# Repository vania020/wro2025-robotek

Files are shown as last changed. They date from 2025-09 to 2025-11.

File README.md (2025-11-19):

# Ruwance - WRO 2025robotekPeru Flag

<p align="center">
  Banner Ruwance
</p>





+ Team Name: **Ruwance**
+ Car Name: **Kyra**
+ Club Name: **Robotek**
+ Team Members: **Isabella Gonzales & Vania Pachas**
+ Coach: **Anthony Valladolid**

---

*Welcome! 🎉* <br>
We are Team Ruwance, proudly representing Perú at the 2025 World Robot Olympiad! This GitHub repository contains the documentation, code, and full development journey of our autonomous vehicle, designed and built to compete in the Future Engineers Challenge.

# Repository Structure
* `t-photos` team photos (official one and funny one)
* `v-photos` photos of our vehicle (from every side, from top and bottom)
* `video` demonstration video link of the robot in the challenges
* `schemes` Wiring diagram with pins and electronic components
* `src` code of the robotic vehicle system
* `models` 3D printed parts and other chassis pieces 
* `other` Extra documentation

# Table of Contents
1. [Meet the Team!](#1-meet-the-team)
   
3. [Vehicle Overview](#2-vehicle-overview)
   + [General Description of the Car](#general-description-of-the-car)
   + [Versions of the Car](#versions-of-the-car)
     
4. [System Setup](#3-system-setup)
   + [Operating Environment Overview](#operating-environment-overview)
   + [Robot Operating System (ROS)](#robot-operating-system-ros-)
   + [Ubuntu](#ubuntu-)
   + [Raspberry Pi](#raspberry-pi-)
     
5. [Mobility Management](#4-mobility-management)
   + [Steering System - Ackermann](#steering-system--ackermann)
   + [Motor and Drivetrain](#motor-and-drivetrain)
   + [3D Pieces](#3d-pieces)
   
6. [Power & Sense Management](#5-power--sense-management)
   + [Power Source](#power-source)
   + [Sensors Integration](#sensors-integration)
   + [BOM (Bill of Materials)](#bom-bill-of-materials)
   + [Wiring Diagram](#wiring-diagram)

7. [Obstacle Management](#6-obstacle-management)
   + [Control Node Structure](#control-node-structure)
   + [Open Challenge](#open-challenge)
   + [Obstacle Challenge](#obstacle-challenge)
     
8. [Assembly Instructions](#7-assembly-instructions)
9. [Performance Videos](#8-performance-videos)
   
<br>

# Main Content

## 1. Meet the Team!
<table>
  <tr>
    <td width="55%" valign="top">
      <strong>Vania Pachas</strong><br><br>
      pencial <i>Responsible for Mechanical Design & Technical documentation</i><br>
       mail vaniaapachas@gmail.com<br>
       location Lima, Perú<br><br>
      Hi!! I'm Vania, an 18-year-old Peruvian passionate about innovation and STEM education. This is my first time in the WRO, and I'm excited to learn and take on this new challenge! I also love dancing salsa, crocheting, watching romcoms, and I’m a Quantum Computing enthusiast :)<br><br>
   
  <td width="45%" align="center">
    Vania
    </td>
  </tr>
  
</table>

<table>
  <tr>
    <td width="55%" valign="top">
      <strong>Isabella Gonzales</strong><br><br>
      pencial <i>Responsible for Electronics and Technical Designer documentation</i><br>
       mail isabellamilagros842@gmail.com<br>
       location Lima, Perú<br><br>
      Hello! My name is Isabella, I'm 16 years old, and I love robotics. I founded Robotek Perú, a club where students can learn robotics and join competitions, and this is my second time at the WRO. My favorite hobbies are singing with my choir, practicing taekwondo, and art. <br><br>
   
  <td width="45%" align="center">
    Isa
    </td>
  </tr>
  
</table>

<br>

> [!NOTE]
> 🤔Why is our team named *Ruwance*?<br><br>
> The name *Ruwance* comes from combining the Quechua word "**ruway**" and the English word "**chance**". Ruway means "to create" or "to do", which really reflects who we are, a team that is always making, building, and experimenting. As students of Robotek from Lima, Peru, we have learned that creativity and resilience are important traits to succeed in and enjoy our robotics journey.

<br>

## 2. Vehicle Overview
This is our car named **Kyra**, it is the result of multiple versions and modifications since 2024:) Since then, we have been studying, learning and testing different methods to improve our car. It has been an interesting and challenging journey in robotics, but every effort was worth it!

<p align="center">
  Vehicle Overview
</p>

### **<ins>General Description of the Car</ins>**
Our autonomous vehicle is built to take on both the Open and Obstacle Challenges at the Future Engineers competition. Running on Ubuntu with ROS, it can process information and make decisions in real time. The car uses an Ackermann steering system and a custom-built chassis to move smoothly through turns and straight paths. A LiDAR sensor helps it detect the field walls, while the camera identifies traffic signs and obstacles. With this setup, the car can adapt its route, count laps, and complete the course efficiently.
<br>

| Front | Left | Right |
| :--: | :--: | :--: |
|  |  |   | 

| Back  | Top  | Bottom |
| :--: | :--: |:--: |
|  |  |   | 
> [!NOTE]
> Visit our [`v-photos`](https://github.com/vania020/wro2025-robotek/tree/main/v-photos) folder for more detailed photos of the car 📸🚗

### **<ins>Versions of the Car</ins>**
Our vehicle has gone through **10 versions** (and since we are always improving, there are still more to come!). It all started with a cardboard prototype, then moved on to acrylic and metal chassis designs, and later, we made personalized adjustments to a HiWonder kit. Along the way, we also experimented with different wheel designs, repositioned components, tested sensors like LiDAR, and finally adopted a new operating environment with ROS and Ubuntu.
<table>  
  <tr>
    <th width="10%">Version</th>
    <th width="40%">Car Photo</th>
    <th width="50%">Description</th>
  </tr>
  
  <!-- Version 1 -->
  <tr>
    <td align="center"><i>Version N°1</i></td>
    <td align="center">
      
    </td>
    <td>
      We built a cardboard prototype to test and understand the Ackermann steering system and wheel movement. This served as a reference to learn about the placement of components and systems.<br><br>
      <a href="v-photos/vehicle-versions/README.md#version-1">➡️ See more photos 🚗</a>
    </td>
  </tr>

  <!-- Version 2 -->
  <tr>
    <td align="center"><i>Version N°2</i></td>
    <td align="center">
    </td>
    <td>
      <br>We cut and incorporated an acrylic chassis and designed/3D-printed housing pieces for the camera, Ackermann system, and other components. The Ackermann used a stepper motor, and to perceive its surroundings, the car relied on infrared sensors and a webcam. 
      <br><br>The main controllers were a Raspberry Pi 4 and an Arduino Nano, powered by a power bank and lithium batteries. The car’s movement was driven by a single motor.<br><br> 
      <a href="v-photos/vehicle-versions/README.md#version-2">➡️ See more photos 🚗</a><br><br>
    </td>
  </tr>

  <!-- Version 3 -->
  <tr>
    <td align="center"><i>Version N°3</i></td>
    <td align="center">
    </td>
    <td>
      <br> We replaced the power bank with a smaller one, adjusted component placement into a two-level car system, and installed new wheels. Lithium batteries were replaced with higher-current ones, and the infrared sensors were moved to the front, so the vehicle could make more precise turns.<br><br>
      <a href="v-photos/vehicle-versions/README.md#version-3">➡️ See more photos 🚗</a><br><br>
    </td>
  </tr>

  <!-- Version 4 -->
  <tr>
    <td align="center"><i>Version N°4</i></td>
    <td align="center">
    </td>
    <td>
    <br> We upgraded the chassis to a modified HiWonder Kit and replaced the infrared sensors with a LiDAR for more accurate obstacle detection. The webcam was also switched to a monocular camera. The original car motor was replaced by two encoder motors, adapted with gears to drive a single wheel in compliance with competition guidelines.<br><br>

For the Ackermann steering, we replaced the stepper motor with a servomotor. On top of that, we moved away from the Arduino Nano and began implementing the ROS framework.<br><br>
<a href="v-photos/vehicle-versions/README.md#version-4">➡️ See more photos 🚗</a><br><br>
    </td>
  </tr>

  <!-- Version 5 -->
  <tr>
    <td align="center"><i>Version N°5</i></td>
    <td align="center">
    </td>
    <td>
      <br>Our main improvement was the chassis. We joined the two bases by drilling them together and carefully organized the components with the Raspberry Pi inside. The LiDAR was placed on top so nothing would block its view, and we also completed and installed the camera housing.<br><br>
      <a href="v-photos/vehicle-versions/README.md#version-5">➡️ See more photos 🚗</a><br><br>
    </td>
  </tr>

  <!-- Version 6 -->
  <tr>
    <td align="center"><i>Version N°6</i></td>
    <td align="center">
    </td>
    <td>
      <br> Wheels were changed to adjust the car’s height so the Lidar could detect walls within the 10 cm range (previously it was too high and failed). The housing material was upgraded from PLA to polycarbonate for greater resistance, and the Open Challenge (autonomous 3 rounds driving) was completed.<br><br>
      <a href="v-photos/vehicle-versions/README.md#version-6">➡️ See more photos 🚗</a><br><br>
    </td>
  </tr>

  <!-- Version 7 -->
  <tr>
    <td align="center"><i>Version N°7</i></td>
    <td align="center">
    </td>
    <td>
      <br> Using our HiWonder kit as the base, we designed and cut a completely new, smaller chassis with personalized mounting holes for all components, new housing pieces were created, and the two-motor system was replaced by a single motor in a gear system.<br><br>
    We also moved from a two-level structure to a single-level layout, placing all the components on the same surface to give the Raspberry Pi better airflow and easier access. The car successfully detected and avoided the first traffic signs.<br><br>
      <a href="v-photos/vehicle-versions/README.md#version-7">➡️ See more photos 🚗</a><br><br>
    </td>
  </tr>

  <!-- Version 8 -->
  <tr>
    <td align="center"><i>Version N°8</i></td>
    <td align="center">
    </td>
    <td>
      <br> <b>Car dimensions:</b> 15 x 23 cm <br><br>
      We 3D-printed new, slimmer front wheels because the original ones stuck out too much from the chassis. A custom housing was also printed for the batteries, and most importantly, the Ackermann steering servo was mounted vertically to save space and allow for a wider turning angle.<br><br>
During previous testing, we realized the LiDAR was struggling to properly detect the walls of the field, so we 3D-printed and implemented a small angled mount to give it a slight tilt.<br><br>
      <a href="v-photos/vehicle-versions/README.md#version-8">➡️ See more photos 🚗</a><br><br>
    </td>
  </tr>

<!-- Version 9 -->
  <tr>
    <td align="center"><i>Version N°9</i></td>
    <td align="center">
    </td>
    <td>
      <br> <b>Car dimensions:</b> 15 x 20 cm <br><br>
In this version, the components were arranged more efficiently to save space. We added a custom housing for the batteries, placed the Pi5 controller on top, and mounted the Raspberry above it, creating a layered system.<br><br>
A new chassis base was printed in MDF, and the Ackermann was moved slightly because, in the previous version, the rack was colliding with the servo. To improve traction, we added a groove to the wheels and printed small cylinders between them to prevent contact with the screws. With these adjustments, the robot managed to complete a lap in <b>20 seconds</b>.<br><br>
      <a href="v-photos/vehicle-versions/README.md#version-9">➡️ See more photos 🚗</a><br><br>
    </td>
  </tr>

  <!-- Version 10 -->
  <tr>
    <td align="center"><i>Version N°10</i></td>
    <td align="center">
    </td>
    <td>
      <br> <b>Car dimensions:</b> 15 x 18 x 16 cm <br><br>
We removed the LiDAR housing because, after testing the robot multiple times, we found that vision worked better without it. We also printed the rear wheels, so now all wheels are the same. We modified the gear system, which allowed the robot to complete the 3 laps faster. It now takes less than 10 seconds to complete an entire lap, and it manages to complete the 3 laps in 28 seconds. The small and big gears were interchanged so that the big gear is directly attached to the motor shaft.<br><br>
  <a href="v-photos/vehicle-versions/README.md#version-10">➡️ See more photos 🚗</a><br><br>
    </td>
  </tr>

</table>

<br>

> [!NOTE]
> Visit our [`vehicle-versions`](v-photos/vehicle-versions/README.md) folder to see photos and videos of our car evolution 🔝

<br>

## 3. System Setup
### **<ins>Operating Environment Overview</ins>**
The operating environment of our robotic car is designed as a structure that connects hardware, software, and middleware into a single functional system, shown in the diagram below:

<p align="center">
  diagram
</p>

### **<ins>Robot Operating System (ROS)</ins>** ROS
ROS is a framework that connects a robot’s software and hardware, making sensors, motors, and programs work together so the robot can perform tasks smoothly. For this project, we use ROS 2 Jazzy, one of the latest versions of ROS 2. You can find the documentation here:  [ROS 2 Documentation: Jazzy](https://docs.ros.org/en/jazzy/index.html)<br>

Without ROS, everything would have to be written in one long, complicated program that’s hard to manage. We can now divide the system into smaller parts, or nodes, that each do one job, making the system easier to build, fix, and expand.<br>

<p align="center">
  Nodes
</p>

> This is an official animation to better understand how nodes work. Each node does one clear job, like moving wheels or reading sensors, and they talk to each other using topics, services, actions, or parameters.
>  In practice, this is the process:
> 1. Sensors send data to ROS 2 by publishing it on topics.
> 2. Other nodes listen to that data, process it, and decide what the car should do.
> 3. Finally, a controller node sends commands, making the car move accordingly.

<br>

*<ins>Why we use ROS?</ins>*<br>

<table>
  <tr>
    <td><b>Sensor & Actuator Integration</b></td>
    <td>
      ROS connects all sensors and actuators in one system, ensuring seamless coordination. 
      This gives our autonomous car continuous information about its surroundings 
      and optimizes overall performance.
    </td>
  </tr>
  <tr>
    <td><b>Environmental Perception with LiDAR</b></td>
    <td>
      Most manufacturers of advanced sensors, such as LiDARs, provide an official package to use their hardware with ROS. In the case of the DTOF STL-19P, the manufacturer provides a package that automatically publishes the LiDAR data so it can be processed afterward.
    </td>
  </tr>
  <tr>
    <td><b>Support with Python</b></td>
    <td>
      ROS is fully compatible with Python, which allows for versatile and high-level code development. In addition, being open-source, it has a large community that provides support and assistance for robot development.
    </td>
  </tr>
  <tr>
    <td><b>Debugging & Simulation</b></td>
    <td>
      ROS includes tools to quickly debug the content published on topics. It also provides tools such as RViz, which allows real-time data visualization, and Gazebo, which enables running simulations.
    </td>
  </tr>
  <tr>
    <td><b>Efficient Simulation & Debugging</b></td>
    <td>
      Virtual environments like 
      <a href="https://gazebosim.org/home">Gazebo</a> let us fine-tune parameters before implementation. 
      Tools like 
      <a href="https://docs.ros.org/en/humble/Tutorials/Intermediate/RViz/RViz-User-Guide/RViz-User-Guide.html">RViz</a> 
      allow real-time visualization of sensor data and car status, making debugging much easier.
    </td>
  </tr>
</table>

<br>

### **<ins>Ubuntu</ins>** UBUNTU
Ubuntu is a popular, free, open-source operating system based on Linux. It is known for being reliable, flexible, and widely used in both research and industry. In our project, we use Ubuntu 24.04 as the **foundation that runs on the Raspberry Pi**.<br>

Ubuntu manages the Raspberry Pi’s resources efficiently, ensuring it runs correctly. It provides drivers and compatibility for sensors and external hardware, making integration easier. Ubuntu also allows us to install and run ROS 2 Jazzy and gives us access to important libraries and tools that simplify tasks such as sensor communication and system development.<br>

We use Ubuntu because of its stability and compatibility with ROS 2 Jazzy. Since ROS 2 packages are officially distributed for Ubuntu, using this operating system guarantees that we can easily install and manage the software needed for our car.
<br><br>

### **<ins>Raspberry Pi</ins>** Raspberry
The Raspberry Pi is a small computer that works as the brain of our car. It is powerful enough to run Ubuntu, ROS 2, and our algorithms in real time. In our project, we use the Raspberry Pi 5, which you can find here: [Raspberry Pi 5](https://www.raspberrypi.com/products/raspberry-pi-5/)<br>

**👉 Set up and configuration**<br>

With the [Raspberry Pi Imager](https://www.raspberrypi.com/software/), we flash Ubuntu 24.04 into the microSD card of the Raspberry. After that, we configure the basics like Wi-Fi, SSH for remote access, and hostname. And finally, we install ROS 2 Jazzy by following these steps: [Installation Ubuntu (deb packages)](https://www.google.com/url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)

| Step 1 | Step 2 | Step 3 | Step 4 |
| :--: | :--: | :--: |  :--: |
|  |  |  |  |

<br>

## 4. Mobility Management  

### <ins>**Steering System – Ackermann**</ins>

<p align="center">
  Ackermann
</p>

Our autonomous car uses an Ackermann steering system, controlled by a **15 kg·cm digital servo**, which provides precise and stable control for navigation and turns.  

The Ackermann steering geometry is designed to reduce tire slip by ensuring that all wheels align as radii of circles that share a common center when the car is turning. This configuration keeps the rear wheels fixed and places the center of rotation along a line extended from the rear axle. To achieve this geometry, the inside front wheel turns at a greater angle than the outside front wheel, allowing smoother and more efficient cornering.

---

### **Our own modifications ⚒️**

In the first versions of the car, we implemented the Ackermann steering system using a custom mechanism. We designed and 3D printed a gear connected to a stepper motor, along with a rack, which is a stick with grooves that fit into the gear teeth. When the motor rotated the gear, the rack would move, which in turn rotated the wheels.  

<p align="center">
  
  
</p>

One of the challenges we faced was the 3D printing process itself. Printing small details such as gear teeth was difficult and often imprecise, which caused problems in the initial prototypes. To solve this, we made the gear teeth larger, and while this worked mechanically, the final design ended up taking too much space inside the chassis.

For this reason, we decided to switch to the system we currently use, which is part of the **HiWonder kit**, adapted to fit in our chassis base. Instead of gears, it uses a system of linkages connected by screws and supported by bearings. These linkages move and transfer the motion to the wheels, achieving the Ackermann steering effect in a more compact way.

<p align="center">
  
</p>

> [!WARNING]
> At first, the Ackermann of the HiWonder kit worked fine — the car could turn and even get through some obstacles. But after a lot of testing, we noticed that whenever the car turned left, the Ackermann didn’t rotate as much as it did when turning right. This made obstacle avoidance harder, especially in the field corners, so we knew we had to make adjustments.

We realized that the servo needed to be repositioned. First, it was placed horizontally under the Ackermann linkages. We brainstormed how to make it more efficient and changed the position of the servomotor, mounting it vertically with the accessory facing downward under the chassis. This way, the linkages could move freely with more angles, and we also freed up extra space for the other components. This new placement also allowed us to reduce the length of the chassis.  

<table>  
  <tr>
    <th width="30%">Initial position</th>
    <th width="30%">Idea</th>
    <th width="30%">Final Position</th>
  </tr>
  <tr>
    <td align="center">
      
    </td>
    <td align="center">
      
    </td>
    <td align="center">
      
    </td>
  </tr>
  <tr>
    <td align="center">Servo mounted horizontally (limited angles)</td>
    <td align="center">Servo repositioned vertically</td>
    <td align="center">Final placement with improved steering</td>
  </tr>
</table>

---

### <ins>**Motor and Drivetrain**</ins>

<p align="center">
  
</p>

The drivetrain of our autonomous car is powered by a **25 mm metal gear DC motor**, chosen for its compact size and high torque. The motor is mounted on the chassis and directly connected to the rear axle through a system of gears, ensuring efficient transfer of power to the wheels.  

Our drivetrain includes a gear system:  
- The large gear is mounted on the motor shaft.  
- This large gear drives a smaller gear connected to the rear axle.  
- The result is an increase in the speed of the wheels.

<p align="center">
  
</p>

During assembly, we noticed a gap between the metal chassis part and the axle supports. This caused instability in the drivetrain. To fix it, we designed custom 3D-printed cylindrical spacers that fill the gap and keep the axle firmly in place. This simple solution reduces vibrations, prevents misalignment, and ensures smoother transmission of power from the motor to the wheels.

<p align="center">
  
</p>

---

### <ins>**3D Pieces**</ins>

This is the 3D model of our vehicle.  
Below, you will find a table with our 3D-printed parts and their descriptions.

<p align="center">
  
</p>

<table align="center" width="100%" style="table-layout: fixed;">
  <thead>
    <tr>
      <th width="30%">Component</th>
      <th width="40%">Preview</th>
      <th width="30%">Folder</th>
    </tr>
  </thead>
  <tbody>
    <tr>
      <td align="center"><b>Vehicle Base</b></td>
      <td align="center">
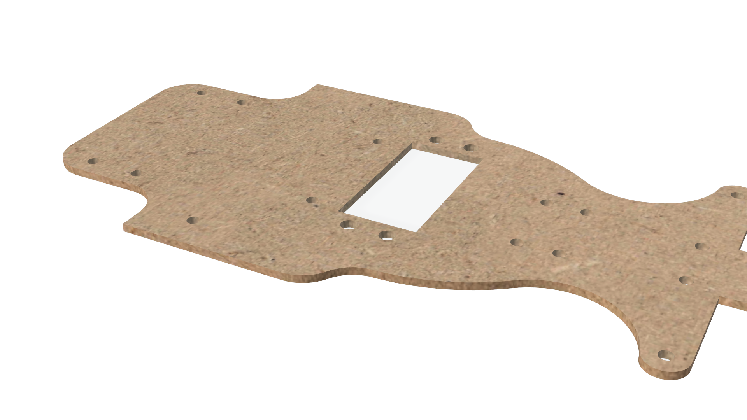
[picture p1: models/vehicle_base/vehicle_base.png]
        
      </td>
      <td align="center">
        <a href="models/vehicle_base/" target="_blank">View</a>
      </td>
    </tr>
    <tr>
      <td align="center"><b>Vehicle Wheels</b></td>
      <td align="center">
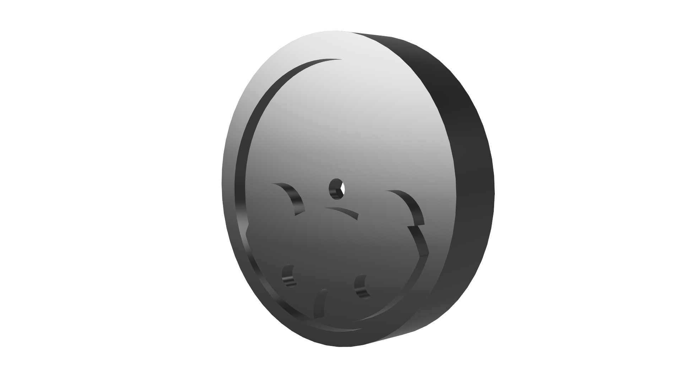
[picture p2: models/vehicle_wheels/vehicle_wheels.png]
        
      </td>
      <td align="center">
        <a href="models/vehicle_wheels/" target="_blank">View</a>
      </td>
    </tr>
    <tr>
      <td align="center"><b>Camera Housing</b></td>
      <td align="center">
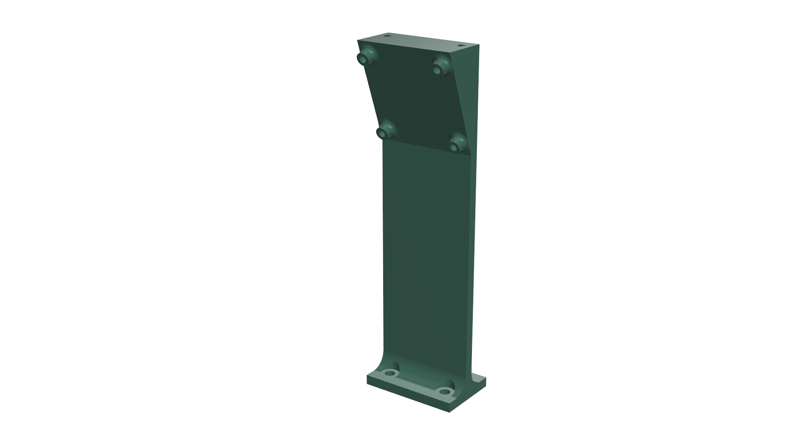
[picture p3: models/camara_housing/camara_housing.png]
        
      </td>
      <td align="center">
        <a href="models/camara_housing/" target="_blank">View</a>
      </td>
    </tr>
       <td align="center"><b>Raspberry Housing</b></td>
      <td align="center">
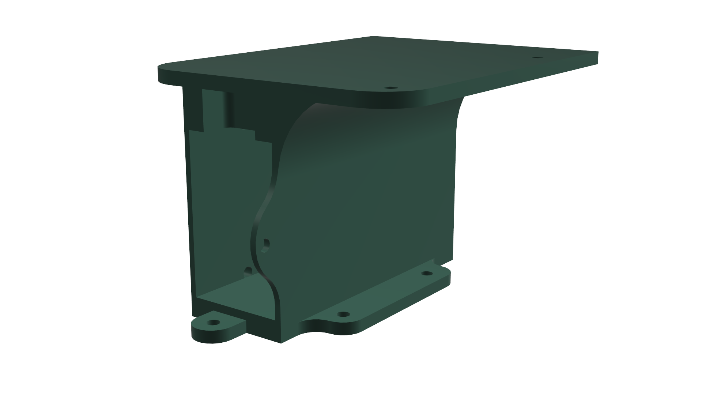
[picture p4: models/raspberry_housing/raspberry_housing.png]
        
      </td>
      <td align="center">
        <a href="models/raspberry_housing/" target="_blank">View</a>
      </td>
    </tr>
  </tbody>
</table>

## 5. Power & Sense Management 

### <ins>**Power Source**</ins>

<p align="center">
  
</p>

Our autonomous car is powered by 7.4V Li-Po batteries (2000mAh, 20C). We chose Li-Po batteries because they provide a high energy density, meaning more power in a small and lightweight package. The battery provides two main energy lines: one for the electronics and another for the motor: <br>

1. **Electronics & Sensors**  
   The battery first connects to the **RRC Lite Controller**, which regulates the power down to a safe **5 V**.  
   From there, it distributes electricity to:  
   - **Raspberry Pi 5** → acts as the brain of the car, running ROS 2 and processing sensor data.  
   - **Digital servomotor** → controls the Ackermann steering system.  
   - **STL-19P TOF LiDAR & monocular camera** → provide vision and distance perception.  

2. **Drive Motor (via L298N Motor Driver)**  
   In parallel, the battery also powers the **L298N motor driver** directly with **7.4 V**.  
   This driver regulates how much current goes to the **25 mm metal DC motor**, which is responsible for moving the car forward.  

By splitting the power into two paths (one regulated for sensitive electronics and one direct for the motor), the system ensures stability. Motors usually demand sudden spikes of current, and separating their supply avoids crashes or interruptions in the Raspberry Pi and sensors.

### <ins>**Sensors Integration**</ins>
To perceive its environment and handle the Future Engineers challenges, the car uses a combination of:  

- **STL-19P TOF LiDAR**: provides 360° distance data.  
- **2DOF Monocular Camera**: detects colors and obstacles.  

Together, these sensors give the robot a better understanding of its environment by combining depth perception with visual input.

### <ins>**STL-19P TOF LiDAR**</ins>

<p align="center">
  
</p>

<br>

Unlike simpler sensors such as ultrasonic or infrared, which measure only in a single direction and have limited precision, the LiDAR sensor is capable of a **360° scanning** and provides precise distance measurements by using laser pulses. It helps the robot map its surroundings over a wide range, detect obstacles, and navigate more accurately in dynamic environments.

<br>

| Characteristic | Vaue |
|---|---|
| Ranging distance | 0.03 – 12 m |
| Size | 38.59 x 38.59 x 34.8 mm |
| Scanning Angle | 360° |
| Scanning Frequency | 5 – 13 Hz |
| Ranging Accuracy | ±45 mm |
| Ranging Frequency | 5000 Hz |

> [!IMPORTANT]
> **📍Placement:**
> The LiDAR was positioned at an altitude of under 10 cm, so it can detect the walls of the path, which are also 10 cm high. This placement ensures the Lidar has a clear view of the obstacles while remaining unobstructed by other components. All other elements on the car were arranged to avoid blocking the Lidar’s line of sight. <br><br>
> 

### <ins>**2DOF Monocular Camera**</ins>

<p align = "center">
  
  </p>
<br>

The 2DOF Monocular Camera complements the LiDAR by adding visual perception. This allows the robot to recognize its environment beyond distance data, enabling future applications such as detecting the obstacles’ colors:

 + **Color detection**: Since graphical color detection is a core part of our  project, the camera can precisely identify various colors on the course. This allows our car to interact with the different traffic signs in the Obstacle challenge.
  + **Spatial awareness through data fusion**: When combining camera data with our sensor, the robot gains a richer understanding of its environment. The camera provides detailed visual context that leads to an adaptable navigation strategy.

> [!IMPORTANT]
> **📍Placement:**
> The camera is located in a special 3D mounting piece with a certain  inclination angle that points to the floor so it can better detect obstacles. At first it was placed at the front of the car but this location provided a limited vision and sticked out of the chassis lenght. See more detailed info of the housing piece in the [`3D Printed Parts`](#3d-printed-parts) section. <br><br> 
> 

### **<ins>BOM (Bill of Materials)</ins>**
| Component | Quantity | Description | Image |
|---|---|---|---|
| Raspberry Pi 5 | 1 | Main processing unit for running **ROS**. Acts as the main brain and the Host Controller of the system, capable of running operating systems and handling complex processing tasks. | Raspberry Pi 5 |
| RRC Lite Controller | 1 | Integrates: ROS expansion board, High-Frequency PID Control, Motor Closed-Loop Control, Servo Control and Feedback, IMU Data Acquisition, Power Status Monitoring, and a Power Switch. | Controller |
| STL-19P TOF Lidar | 1 | Provides precise, 360-degree distance measurements for real-time navigation and obstacle detection in dynamic environments. | Lidar |
| Lidar Adapter Board | 1 | Converts the LiDAR’s UART signals to USB for PC connection and data reading. | Adapter |
| 15 kg.cm Digital Servo | 1 | Provides accurate steering control. | Servo |
| 25MM Metal Gear Motor | 1 | Core drive motor for powering the wheels with torque and speed. | Motor |
| Suitcase Wheel Protector | 4 | Ensures 3d-printed wheels stability and grip on the floor. | tire |
| Monocular Camera | 1 | A camera used for capturing images and videos, can be used for computer vision or live streaming. | Camera |
| L298N Motor Driver | 1 | Controls motor direction and speed from the Raspberry Pi. | Motor Driver |
| Jumper Cables | 4–8 | Electrical connections between the motor driver and Pi. | Jumper Cables |
| USB-USB Cable | 1 | A cable to connect the Raspberry Pi to the camera, Lidar, and Controller. | USB Cable |
| Li-Po Battery 7.4 V 5000mAh 20C | 1 | A lithium polymer battery that provides portable, high-density power. | Battery |

### <ins>**Wiring Diagram**<ins>

The following visual wiring diagram illustrates the **physical connections** between the modules (Raspberry Pi, LiDAR, camera, motor, etc.) using **realistic component images**. It helps visualize the system layout and understand **how components are arranged and linked** in the robot.  

<p align="center">
  
</p>

#### **1. Raspberry Pi 5 Connections**
The Raspberry Pi 5 works as the brain of the car. Its USB ports connect the main sensors and the controller:

+ Camera → provides visual input for detecting traffic signs and colored obstacles.
+ LiDAR → provides distance and wall detection for navigation.
+ RRC Lite Controller → interfaces with the digital servomotor and forwards control signals to the motor driver.

<p align="center">
  
</p>

#### **2. RRC Lite Controller**
The RRC Lite Controller acts as a bridge between the Raspberry Pi and the actuators. It regulates incoming power from the Li-Po battery (down to a safe 5 V) and distributes it to:  
- The **Raspberry Pi 5**  
- The **digital servomotor** for Ackermann steering  

It also handles communication with the motor driver to send PWM control signals.

---

#### **3. Motor Driver and DC Motor**
The **L298N Motor Driver** is powered directly by the **7.4 V Li-Po battery**.  
- It regulates both the **speed** and **direction** of the **25 mm metal gear DC motor**.  
- The motor then powers the rear axle through a gear reduction system, increasing torque for smoother acceleration.  

---

#### **4. Power Source**
The **7.4 V Li-Po battery** supplies energy to the entire system, split into two paths:  
- **Direct line (7.4 V):** powers the L298N motor driver and DC motor.  
- **Regulated line (via RRC Lite Controller):** delivers 5 V to the Raspberry Pi, servomotor, and sensors.  

<br>

This is also a diagram that shows the **electrical wiring** and pin-level connections between all components — including power lines, GPIOs, and communication ports. It focuses on **signal paths and voltage levels** rather than physical appearance.  

<p align="center">
  
</p>

> [!NOTE]
> Visit our [`schemes`](https://github.com/vania020/wro2025-robotek/tree/main/schemes) folder to access all of our diagrams and schemes 🔑🚗

## 6. Obstacle Management 

### <ins>**Control Node Structure**</ins>

Since we use ROS 2 as the middleware that connects all the components of our autonomous vehicle, there isn't a single code that runs either the Open Challenge or the Obstacle Challenge. Instead, the system is built as a collection of independent but interconnected ROS 2 nodes, each performing a specific function such as reading the camera, processing LiDAR data, or controlling the motors. These nodes communicate constantly through topics and messages, allowing the car to behave as a cohesive, intelligent system.

You can access our custom node codes here:
<br>

| Node | Code Description | Function |
|---|---|---|
| 🛰️ Acker LiDAR Node | [`acker_lidar_node`](./src/acker_lidar_node) | Processes LiDAR scans and controls the robot. |
| 🎥 Camera Node | [`camara`](./src/camara) | Detects obstacles and colors. |
| ⚙️ Motor Node | [`motor`](./src/motor) | Sends PWM signals to control wheel speed. |

<p align="center">
  
</p>

This table better explains our ROS topics and messages:

| **Node** | **Role** | **Topic** | **Message Type** | **What It Transmits** |
| --- | --- | --- | --- | --- |
| **LiDAR Node** | Publisher | `/scan` | `sensor_msgs/LaserScan` | It sends 360° distance readings from the LiDAR; each value represents how far an obstacle is at a given angle. |
| **Camera Node** | Publisher | `/obstaculos` | `std_msgs/String` | It publishes the detected obstacle color in a text form: (`rojo`, `verde`, or `ninguno`), which defines how the main controller adjusts the steering setpoint. |
| **AckerLidar Node** *(Main Controller)* | Central Controller | `/motor_vel`, `/positionServo` | `std_msgs/Float32`, `ros_robot_controller_msgs/SetAckerServoState` | `/motor_vel`: Motor duty cycle (speed %). `/positionServo`: Steering position (PWM in µs) for Ackermann control. |
| **Motor Node** | Subscriber | `/motor_vel` | `std_msgs/Float32` | Receives motor velocity commands from the main controller and translates them into PWM signals for the DC motor driver (L298N). |
| **Raspberry Pi 5 Controller Node** | Subscriber | `/positionServo` | `ros_robot_controller_msgs/SetAckerServoState` | Executes servo position commands and moves the front wheels to reach the target angle. |
| **RRC Controller Button** | Publisher | `/button` | `ros_robot_controller_msgs/ButtonState` | Sends an activation signal when the onboard button is pressed, starting the robot’s control loop. |

### **What is a Message type?**

A **message type** is like a template that defines **what kind of data** is sent through a *topic*. For example, ROS already includes many built-in types, such as:

* `std_msgs/String` → used to send text.
* `std_msgs/Float32` → used to send a decimal number.
* `sensor_msgs/LaserScan` → used to send LiDAR data (distance readings around 360°).
* `geometry_msgs/Twist` → used to send linear and angular velocities (very common in mobile robots).
* And you can also have **custom message types**, like the ones included in your own package `ros_robot_controller_msgs`.

### **Important clarifiactions**

* For simplicity, **some topic names were shortened** in the diagrams.

  * The real ROS topic `/ros_robot_controller/acker_servo/set_state` is represented as **`/positionServo`**.
  * The real ROS topic `/ros_robot_controller/button` is represented as **`/button`**.

* The button input `/ros_robot_controller/button` is processed internally by the main node and does not appear as a separate node because it doesn’t exchange messages with others.

* The naming convention was simplified only for documentation clarity; all logic and connections in the code remain unchanged.

* The **AckerLidar Node** acts as the core controller that links everything:
  it subscribes to LiDAR and camera data, processes the PID control, and publishes both the steering and velocity commands.

> [!NOTE]
> If you would like to see a detailed description and explanation of the code behind each node, please visit our [`src`](https://github.com/vania020/wro2025-robotek/tree/main/src) folder 🖥️🚗
> 

---

### <ins>**Open Challenge**</ins>

The **Open Challenge** is the first autonomous driving test. In this stage, the robot must complete three laps **without any external input** relying only on its onboard **LiDAR sensor**, **PID controller**, and **Ackermann steering system**. The goal is to keep the car centered between the inner and external walls of the challenge during the entire lap. To achieve that, the robot constantly measures two key distances: **D₁** → Distance from the car to the **left wall** and **D₂** → Distance from the car to the **right wall**

The **control goal** is defined by the equation:

> **D₁ - D₂ = 0**  
> *(Setpoint = 0 → car is centered)*

When this balance holds true, it means that both walls are equidistant, and the car is aligned in the center of the track.

<p align="center">
  
</p>

### **How It Works: LiDAR + Control Loop**

The LiDAR sensor scans the surrounding environment in real time, detecting obstacles and measuring the distances around the car. From these scans, two zones are analyzed, one on the **left** and one on the **right** to extract D₁ and D₂.

These values are sent to the **AckerLidarNode**, the main control node in charge of:
- Reading and processing LiDAR data  
- Computing the distance difference `error = D₁ - D₂`  
- Sending control signals to the **steering** and **motor** nodes

The logic is the following:  
1. If **D₁ > D₂**, the car is too close to the right wall → it turns slightly **left**.  
2. If **D₁ < D₂**, the car is too close to the left wall → it turns slightly **right**.  
3. If **D₁ = D₂**, the car is centered → it continues straight.

This process runs in a **PID feedback loop**, where:
- The **P (Proportional)** term corrects small deviations quickly.  
- The **I (Integral)** term reduces long-term bias (not always needed).  
- The **D (Derivative)** term prevents oscillations and overshoot.  

The result is a **smooth, stable trajectory** that keeps the car aligned throughout the race.

<div align="center">
  
</div>

### **Open Challenge Flowchart**

 

#### Step-by-Step Description

1. **Start Robot & Initialization**  
   ROS2 nodes are launched: the LiDAR begins scanning, and the control node initializes all parameters (PID gains, setpoint, motor topics).

2. **Continuous Loop**  
   The system enters a continuous loop (`while rclpy.ok()`), running dozens of times per second. Each cycle updates sensor readings and steering actions.

3. **LiDAR Scan Environment**  
   The sensor performs a 360° scan to detect the walls and extract points on both sides of the track.

4. **Extract Wall Distances (D₁, D₂)**  
   The algorithm filters the LiDAR data to isolate the left and right regions, computes the average distance for each, and updates D₁ and D₂.

5. **Compute Error (D₁ - D₂)**  
   The difference between these distances represents how “off-center” the car is from the ideal middle of the lane.

6. **PID Steering Adjustment**  
   The PID controller processes this error and outputs an angle correction, which is sent to the **servo motor** using an Ackermann steering model.

7. **Update Lap Counter**  
   The control node counts laps based on internal flags or distance traveled (depending on the implementation in the ROS2 package).

8. **3 Laps Completed → Stop Vehicle**  
   After completing three full laps, the system safely reduces speed and stops the motor node.

### **Nodes and Communication**

During the Open Challenge, three ROS2 nodes work together in real time:

| Node | Role | Description |
|---|---|---|
| **`AckerLidarNode`** |Main Control Node | Subscribes to LiDAR data, calculates the distance difference, runs the PID controller, and sends steering/motor commands. |
| **`MotorPWMNode`** | Motor Control | Receives speed values (`Float32`) and controls the DC motor through PWM signals, ensuring smooth acceleration. |
| **`SetAckerServoState`** | Steering Control | Adjusts the steering servo angle according to PID output, maintaining Ackermann kinematics. |

---

### <ins>**Obstacle Challenge**</ins>

<p align="center">
  
</p>

### **Obstacle Challenge Flowchart**

<p align="center">
  
</p>

<br><br>
## 7. Assembly Instructions 

### **Ackermann System**
+ To build the Ackermann system on the car, first screw the fixed parts that attach the system to the base.
+ Next, attach the two movable pieces that steer the wheels to the sides of the fixed part. Make sure these pieces can still rotate freely. Each of these pieces has two holes use the hole that is closer to the wheels.
+ Then, connect the wheel pieces with a linkage that has bearings on both ends. The bearings should be screwed into the other holes of the wheel pieces, forming a movable, half-rectangular structure.
+ Attach a second linkage, identical to the first but shorter, to one side of the system. This linkage connects to one of the holes on the wheel pieces, the same ones linked to the bearings of the first linkage. This shorter linkage will move the steering system and must be connected directly to the servo motor, which should be mounted vertically on the base.
+ Important: The servo’s output shaft and the side where the second linkage is attached should be on opposite sides.
Finally, attach the wheel hubs, the parts that hold the actual wheels, to the movable pieces via bearings. These bearings should allow the wheels to rotate freely.
 
### **Motor System**
+ Screw the motor mount, which is the piece that holds both the motor and its axle, onto the base. Then, screw the motor to this mount.
+ Insert the axle into the mount. The mount has two circular openings that the axle passes through. The axle should be supported by two bearings, which keep it centered, and two locking rings, which prevent side movement.
+ Once the axle is in place, connect the motor shaft and the axle using spacers, ensuring they do not collide with the motor screws.
 
### **Housings**
After both systems are assembled, install the housings on the top side of the base. Mount the camera, LiDAR, batteries, and Raspberry Pi according to the model layout:
+ The LiDAR housing goes at the front, ensuring its field of view is unobstructed.
+ The camera housing goes right behind the LiDAR housing, which it’s taller, so its view remains clear.
+ The battery and Raspberry Pi housings go behind them, forming a sort of ceiling above the servo motor that protrudes from the base.
 
### **Electronics**
Finally, install all electronic components, attaching them to their designated housings and connecting them according to the wiring diagram.

<br><br>
## 8. Performance Videos 

<div align="center">

| Challenge | YouTube Video |
|---|---|
| RUWANCE 2 | <a href="https://youtu.be/wX616LgmSGo?si=lTu6liZ41IkfMFjK">Watch on YouTube 🎥</a> |
| RUWANCE 1 | <a href="https://youtu.be/DUVe36ZpR18?si=IGmmhTL5FZdeEi8m">Watch on YouTube 🎥</a> |

</div>

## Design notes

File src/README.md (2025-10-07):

RUWANCE (2)

<br>
<br>

| Node | Code Description | Function |
|---|---|---|
| 🛰️ Acker LiDAR Node | [`acker_lidar_node`](./acker_lidar_node/) | Reads and processes LiDAR scans. |
| 🎥 Camera Node | [`camara`](./camara) | Detects obstacles and colors. |
| ⚙️ Motor Node | [`motor`](./motor) | Sends PWM signals to control wheel speed. |

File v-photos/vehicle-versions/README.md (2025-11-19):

RUWANCE (2)

<details>
  <summary>🚗 Version 1</summary>

| Version1_1 | Version1_2|
|---|---|
|  | Version1_4 |
| Version1_5 | Version1_6 |

</details>

<details>
  <summary>🚗 Version 2</summary>

|Version2_1 |Version2_2|
|---|---|
| Version2_3 |Version2_4|
|Version2_5 | Version2_6|

</details>

<details>
  <summary>🚗 Version 3</summary>

|Version_3 | Version3_1|
|---|---|
| <video src="https://github.com/user-attachments/assets/6eacc7fe-c0a3-41d3-8a91-9b308436cb5c" controls width="300"></video> | <video src="https://github.com/user-attachments/assets/b95e6bf3-f4a5-498e-a463-fc855877e273" controls width="300"></video> |

</details>

<details>
  <summary>🚗 Version 4</summary>

|Version4_2 |Version4_1 |
|---|---|
|Version4_3| Version4_4|
| Version4_5 | Version4_6 |

</details>

<details>
  <summary>🚗 Version 5</summary>

| Version5_1|Version5_2 |
|---|---|
|Version5_3| Version5_4|
| Version5_5| Version5_6|

</details>

<details>
  <summary>🚗 Version 6</summary>

| Version_6 | Version_6|
|---|---|
| <video src="https://github.com/user-attachments/assets/f36f642c-d2df-405a-8f7c-5bf95a052c07" controls width="300"></video> | <video src="https://github.com/user-attachments/assets/267cbbfe-3e4c-4b7d-ae23-0c0a9ceb5a3c" controls width="300"></video> |

</details>

<details>
  <summary>🚗 Version 7</summary>

| Version7_3|Version7_4|
|---|---|
| <video src="https://github.com/user-attachments/assets/7f9c4723-8aec-46f7-922d-036e9eb88da0" controls width="300"></video> | <video src="https://github.com/user-attachments/assets/6fb51656-d793-4519-9e96-b810b5ebbbea" controls width="300"></video> |

</details>

<details>
  <summary>🚗 Version 8</summary>

| Version8_1|Version8_2|
|---|---|
| Version8_3| Version8_4 |
|version8| ackermann |

</details>

<details>
  <summary>🚗 Version 9</summary>

|  ||
|---|---|
| <video src="https://github.com/user-attachments/assets/e9397982-21c5-499b-800a-85f2eb6be0a0" controls width="300"></video> | <video src="https://github.com/user-attachments/assets/c0ddc48a-6913-4427-ab60-49d417406f30" controls width="300"></video> |

</details>

<details>
  
  <summary>🚗 Version 10</summary>

|||
|---|---|
||  |

</details>

</details>

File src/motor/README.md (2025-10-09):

## Code Explanation — [`motor.py`](./motor.py) 

### ✅ **Summary**

This code creates a motor controller node for ROS 2. It listens to a topic `/motor_vel` where another node sends the desired speed. That number is converted into a PWM signal that the Raspberry Pi sends through a GPIO pin to the motor driver, making the car move faster or slower. When the program ends, it stops the PWM and powers down the motor safely.

---

## 1. Importing Required Libraries

```python
from rclpy.node import Node
from std_msgs.msg import Float32
import lgpio
import time
import threading
import rclpy
```

* `rclpy` and `Node`: allow the creation of a ROS 2 node.
* `Float32`: message type used to receive the motor speed (a decimal number).
* `lgpio`: provides access to the Raspberry Pi’s GPIO pins.
* `threading` and `time`: allow continuous background execution and precise time control.

These imports enable both the ROS 2 communication layer and the low-level GPIO control.

---

## 2. Defining the Node Class

```python
class MotorPWMNode(Node):
    def __init__(self):
        super().__init__('motor_pwm_node')
```

Every ROS 2 component is implemented as a *node*.
Here, a new node called **`motor_pwm_node`** is initialized.
This gives the process an identity in the ROS 2 network so other nodes can communicate with it.

---

## 3. Configuring the PWM Parameters

```python
self.CHIP = 4
self.PWM_PIN = 12  # BCM18 (physical pin 12)
self.freq = 1000   # 1000 Hz
self.period = 1 / self.freq
self.duty = 0.0
```

* **`PWM_PIN`** = GPIO 18 (physical pin 12) is used to output the PWM signal.
* **`freq`** = 1000 Hz → the signal turns ON and OFF one thousand times per second.
* **`period`** = the time length of a single PWM cycle.
* **`duty`** = how long the signal stays ON during each cycle (from 0.0 to 1.0).

A duty of 0 means no power (motor off), while 1.0 means full power.

---

## 4. Initializing the GPIO Output

```python
self.h = lgpio.gpiochip_open(self.CHIP)
lgpio.gpio_claim_output(self.h, self.PWM_PIN)
```

The script opens the GPIO controller and claims the selected pin as an **output**.
This ensures that the pin is ready to send electrical signals rather than receive them.

---

## 5. Subscribing to the `/motor_vel` Topic

```python
self.subscription = self.create_subscription(
    Float32,
    '/motor_vel',
    self.vel_callback,
    10
)
```

The node subscribes to the topic `/motor_vel`, expecting `Float32` messages.
Whenever another ROS 2 node publishes a new speed value, the function **`vel_callback()`** is triggered.
Typical values range between 0 and 100, representing the motor’s desired speed in percent.

---

## 6. Starting a Background Thread

```python
self.running = True
self.pwm_thread = threading.Thread(target=self.pwm_loop)
self.pwm_thread.start()
```

Generating a stable PWM signal requires precise timing.
To avoid blocking ROS 2 communications, the script runs the PWM generation in a **separate thread** (`pwm_loop`).
This allows ROS 2 to continue processing messages while PWM pulses are produced continuously.

---

## 7. Processing Speed Commands

```python
def vel_callback(self, msg):
    self.duty = max(0.0, min(1.0, msg.data / 100.0))
    self.get_logger().info(f"Duty updated: {self.duty * 100:.1f}%")
```

Each time a new message arrives on `/motor_vel`:

1. The numeric value (e.g., 50.0) is converted from 0–100 to a duty cycle between 0.0 and 1.0.
2. The value is limited to prevent out-of-range errors.
3. A short log message confirms the update.

For example, sending `60` on the topic sets the PWM duty cycle to 0.6 (60% power).

---

## 8. Generating the PWM Signal

```python
def pwm_loop(self):
    while self.running:
        if self.duty > 0:
            lgpio.gpio_write(self.h, self.PWM_PIN, 1)
            time.sleep(self.period * self.duty)
            lgpio.gpio_write(self.h, self.PWM_PIN, 0)
            time.sleep(self.period * (1 - self.duty))
        else:
            lgpio.gpio_write(self.h, self.PWM_PIN, 0)
            time.sleep(self.period)
```

This loop runs continuously while the node is active:

* If the motor should move (`duty > 0`), the pin alternates between
  **HIGH** (on) for part of the period and **LOW** (off) for the rest.
* If `duty = 0`, the pin remains LOW, stopping the motor.

The faster this ON/OFF cycle, the smoother the motor speed.

---

## 9. Stopping the Node Safely

```python
def destroy_node(self):
    self.running = False
    self.pwm_thread.join()
    lgpio.gpio_write(self.h, self.PWM_PIN, 0)
    lgpio.gpiochip_close(self.h)
    super().destroy_node()
```

When the node shuts down (for example, when the user presses Ctrl + C):

* The PWM thread stops running.
* The output pin is set LOW so the motor immediately stops.
* The GPIO controller is closed properly.
* The node itself is destroyed.

This prevents the motor from staying active after program termination.

---

## 10. Main Entry Point

```python
def main(args=None):
    rclpy.init(args=args)
    node = MotorPWMNode()
    try:
        rclpy.spin(node)
    except KeyboardInterrupt:
        pass
    finally:
        node.destroy_node()
        rclpy.shutdown()
```

The `main()` function initializes ROS 2, creates the node, and keeps it alive using `rclpy.spin()`.
When the user interrupts execution, it performs a clean shutdown and powers the motor off safely.

This structure allows the Raspberry Pi to control the motor’s speed smoothly and safely while remaining fully integrated with the ROS 2 communication framework.

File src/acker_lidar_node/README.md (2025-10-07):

## Code Explanation — [`acker_lidar_node.py`](./acker_lidar_node.py) 

### ✅ **Summary**

This node uses **LiDAR data** and a **PID controller** to keep the robot centered between walls or obstacles. It reacts to **red and green signals** by shifting its path slightly left or right. The car only starts after the **button** is pressed and continuously adjusts steering while moving.

---

### 1. Libraries and Initialization

```python
import rclpy
from rclpy.node import Node
from sensor_msgs.msg import LaserScan
from std_msgs.msg import Float32, String
from ros_robot_controller_msgs.msg import SetAckerServoState, ButtonState
import numpy as np
import time
```

**Explanation:**
This code imports all the essential ROS 2 and Python libraries:

* **rclpy** – The main ROS 2 client library for Python. It lets us create publishers, subscribers, and timers.
* **sensor_msgs.msg.LaserScan** – Used to receive LiDAR readings.
* **std_msgs.msg.Float32 and String** – Allow us to send motor velocity and string messages between nodes.
* **ros_robot_controller_msgs.msg.SetAckerServoState, ButtonState** – Custom messages for controlling the steering servo and reading the start button.
* **numpy** – For calculations like averages and filtering LiDAR data.
* **time** – For simple timing operations inside the node.

---

### 2. Class Definition and Publishers

```python
class AckerLidarController(Node):
    def __init__(self):
        super().__init__('acker_lidar_node')
```

**Explanation:**
Here we define a ROS 2 node called **`AckerLidarController`**, which will handle:

* Reading **LiDAR data**.
* Running a **PID control** loop to keep the car centered.
* Publishing commands to the **servo** (for steering) and the **motor** (for speed).

Then we create **publishers**:

```python
self.acker_publisher = self.create_publisher(SetAckerServoState, '/ros_robot_controller/acker_servo/set_state', 10)
self.vel_pub = self.create_publisher(Float32, '/motor_vel', 10)
```

These send:

* **Servo positions** to `/ros_robot_controller/acker_servo/set_state`
* **Motor speed (PWM duty cycle)** to `/motor_vel`

---

### 3. Subscriptions

```python
self.scan_subscription = self.create_subscription(LaserScan, '/scan', self.scan_callback, 10)
self.button_subscription = self.create_subscription(ButtonState, '/ros_robot_controller/button', self.button_callback, 10)
self.obst_subscription = self.create_subscription(String, '/obstaculos', self.obst_callback, 10)
```

**Explanation:**
The node listens to three topics:

* **`/scan`** → LiDAR readings from the 360° sensor.
* **`/ros_robot_controller/button`** → The start button on the car.
* **`/obstaculos`** → A topic that tells if there’s a “green” or “red” obstacle (used to bias turning).

---

### 4. PID Controller Setup

```python
self.Kp = 1000.0
self.Ki = 0.005
self.Kd = 200.0
```

**Explanation:**
The **PID (Proportional–Integral–Derivative)** controller keeps the car centered between the walls.

* **Kp**: reacts to current error
* **Ki**: corrects long-term drift
* **Kd**: smooths quick changes

It calculates how much the car should turn the servo left or right based on the **distance difference** from LiDAR.

---

### 5. Setpoint Adjustment Based on Obstacles

```python
self.declare_parameter('sp_step', 0.70)
self.sp_step = float(self.get_parameter('sp_step').value)
self.sp_diff = 0.0
```

**Explanation:**
The **setpoint (sp_diff)** shifts slightly when the system detects an obstacle.
If a **green obstacle** is found → the car moves slightly **left**.
If a **red obstacle** is found → the car moves slightly **right**.

---

### 6. Button Activation

```python
def button_callback(self, msg):
    self.button_pressed = True
    self.vel_pub.publish(Float32(data=90.0))
```

**Explanation:**
When the **start button** is pressed, the node activates the car’s motor (starting with a safe initial duty of 90%).

---

### 7. Reading LiDAR Data

```python
def scan_callback(self, msg: LaserScan):
    ...
    left_avg = sum(valid_left) / len(valid_left)
    right_avg = sum(valid_right) / len(valid_right)
    self.current_error = (right_avg - left_avg) - self.sp_diff
```

**Explanation:**
The LiDAR readings are split into **left** and **right** zones.
The node computes the **average distance** on each side and finds the **error** between them.
If `error = 0`, the car is centered.
If `error > 0`, it’s too close to the left wall → turn right.
If `error < 0`, it’s too close to the right wall → turn left.

---

### 8. PID Output and Servo Control

```python
def pid_control(self):
    proportional = self.Kp * self.current_error
    self.integral += self.Ki * self.current_error
    derivative = self.Kd * (self.current_error - self.previous_error)
    output = proportional + self.integral + derivative
    self.previous_error = self.current_error
    return output
```

**Explanation:**
The PID calculates a control value called **`output`**, which is used to set the servo angle.
This keeps the robot stable and smooth while following the corridor or avoiding walls.

---

### 9. Control Loop

```python
def control_loop(self):
    if self.button_pressed:
        steering = self.pid_control()
        position = int(self.center_position - steering)
        position = min(max(position, self.min_position), self.max_position)
        self.send_servo_command(position, 0.1)
        self.vel_pub.publish(Float32(data=100.0))
```

**Explanation:**
Every 0.1 seconds, the control loop runs:

1. Calculates the new servo position from PID.
2. Sends the command to the servo.
3. Keeps the car moving with a constant speed (100 duty).

If no button is pressed, the car stays stopped.

---

### 10. Main Function

```python
def main(args=None):
    rclpy.init(args=args)
    controller = AckerLidarController()
    rclpy.spin(controller)
```

**Explanation:**
This is where the ROS 2 node actually starts running.
It keeps the controller active, listening to LiDAR and button inputs, and publishing movement commands.

---

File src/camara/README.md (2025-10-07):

## Code Explanation — [`camara_node.py`](./camara.py) 

### ✅ **Summary**

This camera node is a **simple real-time color detector** for the robot’s front camera. It identifies **red** and **green** obstacles, filters noise with HSV and morphology, and sends results through `/obstaculos` for the other nodes (like LIDAR or main control) to act on.

---

### **1. Libraries and Imports**

```python
import rclpy
from rclpy.node import Node
from rclpy.qos import QoSProfile, ReliabilityPolicy, HistoryPolicy
from sensor_msgs.msg import Image
from std_msgs.msg import String
from cv_bridge import CvBridge
import cv2
import numpy as np
```

**Explanation:**

* `rclpy` → the main ROS 2 Python client library.
* `Node` → allows us to create ROS 2 nodes.
* `QoSProfile`, `ReliabilityPolicy`, and `HistoryPolicy` → manage how image data is transmitted (best effort, last N frames, etc.).
* `Image` → message type that contains the camera frames.
* `String` → simple message type used to publish obstacle color (“red”, “green”, “free”).
* `CvBridge` → converts ROS images into OpenCV images.
* `cv2` and `numpy` → handle image processing and numeric operations.

---

### **2. Node Definition**

```python
class ColorObstacleDetector(Node):
    """
    Subscribes: /usb_cam/image_raw
    Publishes: /obstaculos  ->  "rojo" | "verde" | "libre"

    - Detects colored obstacles using HSV filters.
    - Keeps last detected color for a short time after losing it.
    """
```

**Explanation:**
This node listens to the camera image feed and classifies what it sees into three categories:

* **red obstacle**
* **green obstacle**
* **free (no obstacle)**

It uses **color segmentation** in the HSV color space and smooths out false detections using several frames in a row.

---

### **3. Initialization and Parameters**

```python
def __init__(self):
    super().__init__('color_obstacle_detector')

    self.declare_parameter('min_area', 1400)
    self.declare_parameter('consecutive_required', 3)
    self.declare_parameter('hold_seconds', 1.0)

    self.min_area = int(self.get_parameter('min_area').value)
    self.consecutive_required = int(self.get_parameter('consecutive_required').value)
    self.hold_seconds = float(self.get_parameter('hold_seconds').value)
```

**Explanation:**

* `min_area`: Minimum pixel area for a color blob to count as an obstacle.
* `consecutive_required`: Number of consecutive frames required to confirm detection (to avoid flicker).
* `hold_seconds`: Keeps the last detected color even if it temporarily disappears.

---

### **4. HSV Color Ranges**

```python
# Green
self.lower_green = np.array([45, 0, 0], dtype=np.uint8)
self.upper_green = np.array([85, 255, 255], dtype=np.uint8)

# Red (two ranges because HSV red wraps around)
self.lower_red1 = np.array([0, 50, 50], dtype=np.uint8)
self.upper_red1 = np.array([8, 255, 255], dtype=np.uint8)
self.lower_red2 = np.array([170, 40, 40], dtype=np.uint8)
self.upper_red2 = np.array([179, 255, 255], dtype=np.uint8)
```

**Explanation:**
These values define how “red” and “green” appear in HSV color space.
The red color is split into **two intervals** because it appears on both ends of the HSV hue circle (0–8 and 170–179).

---

### **5. Subscriptions and Publishers**

```python
self.bridge = CvBridge()

image_qos = QoSProfile(
    reliability=ReliabilityPolicy.BEST_EFFORT,
    history=HistoryPolicy.KEEP_LAST,
    depth=10,
)

self.image_sub = self.create_subscription(
    Image, '/usb_cam/image_raw', self.image_callback, image_qos
)
self.pub = self.create_publisher(String, '/obstaculos', 10)
```

**Explanation:**

* The node **subscribes** to `/usb_cam/image_raw` to get live images from the camera.
* It **publishes** the detection result (`rojo`, `verde`, or `libre`) to `/obstaculos`.
* The QoS settings make sure it only keeps the most recent frames (avoiding lag).

---

### **6. State Variables**

```python
self.green_count = 0
self.red_count = 0
self.last_label = 'libre'
self.last_detect_time = None
```

**Explanation:**

* `green_count` and `red_count` track how many frames a color was seen consecutively.
* `last_label` stores the most recent detected color.
* `last_detect_time` remembers when that color was last seen (for the “hold” effect).

---

### **7. Image Callback**

```python
def image_callback(self, msg: Image):
    try:
        frame = self.bridge.imgmsg_to_cv2(msg, desired_encoding='bgr8')
    except Exception as e:
        self.get_logger().error(f'CvBridge error: {e}')
        return

    hsv = cv2.cvtColor(frame, cv2.COLOR_BGR2HSV)
```

**Explanation:**
Every time the camera sends a new frame, this function runs.
It converts the ROS image message into an OpenCV image and then into HSV format for easier color detection.

---

### **8. Creating the Color Masks**

```python
mask_green = cv2.inRange(hsv, self.lower_green, self.upper_green)
mask_red = cv2.bitwise_or(
    cv2.inRange(hsv, self.lower_red1, self.upper_red1),
    cv2.inRange(hsv, self.lower_red2, self.upper_red2)
)

kernel = np.ones((7, 7), np.uint8)
mask_green = cv2.morphologyEx(mask_green, cv2.MORPH_OPEN, kernel, iterations=2)
mask_green = cv2.morphologyEx(mask_green, cv2.MORPH_CLOSE, kernel, iterations=2)
mask_red = cv2.morphologyEx(mask_red, cv2.MORPH_OPEN, kernel, iterations=2)
mask_red = cv2.morphologyEx(mask_red, cv2.MORPH_CLOSE, kernel, iterations=2)
```

**Explanation:**

* Creates **binary masks** that highlight only green or red pixels.
* The morphological operations (`OPEN` and `CLOSE`) remove small noise and fill small holes, making detection more stable.

---

### **9. Detecting Color Areas**

```python
green_area = self._max_contour_area(mask_green)
red_area = self._max_contour_area(mask_red)
green_ok = green_area >= self.min_area
red_ok = red_area >= self.min_area
```

**Explanation:**

* Finds the largest blob (contour) of each color.
* Only considers it valid if the area is above `min_area`.
* This prevents false detections from small dots or reflections.

---

### **10. Decision Logic**

```python
self.green_count = self.green_count + 1 if green_ok else 0
self.red_count = self.red_count + 1 if red_ok else 0
g_ready = self.green_count >= self.consecutive_required
r_ready = self.red_count >= self.consecutive_required
```

**Explanation:**
If a color appears several frames in a row, it becomes a confirmed detection.
This prevents false positives caused by lighting changes or fast camera motion.

---

### **11. Publishing the Result**

```python
if g_ready or r_ready:
    if g_ready and r_ready:
        decided_label = 'rojo' if red_area >= green_area else 'verde'
    elif r_ready:
        decided_label = 'rojo'
    else:
        decided_label = 'verde'
    self.last_label = decided_label
    self.last_detect_time = now
else:
    if self.last_detect_time and (now - self.last_detect_time) <= self.hold_seconds:
        decided_label = self.last_label
    else:
        decided_label = 'libre'

self.pub.publish(String(data=decided_label))
self.get_logger().info(f"/obstaculos: {decided_label}  (red={red_area}, green={green_area})")
```

**Explanation:**

* Chooses which color is currently dominant and publishes it.
* If no obstacle is seen but the last detection was recent, it “remembers” that color for a few moments (the **hold time**).
* Publishes the final decision to `/obstaculos`.

---

### **12. Helper Function**

```python
@staticmethod
def _max_contour_area(mask: np.ndarray) -> int:
    contours, _ = cv2.findContours(mask, cv2.RETR_EXTERNAL, cv2.CHAIN_APPROX_SIMPLE)
    return 0 if not contours else int(max(cv2.contourArea(c) for c in contours))
```

**Explanation:**
Finds all the shapes (contours) in the binary mask and returns the largest one’s area.

---

### **13. Main Function**

```python
def main(args=None):
    rclpy.init(args=args)
    node = ColorObstacleDetector()
    try:
        rclpy.spin(node)
    except KeyboardInterrupt:
        pass
    finally:
        node.destroy_node()
        rclpy.shutdown()

if __name__ == '__main__':
    main()
```

**Explanation:**
This is the standard entry point in ROS 2.
It initializes the system, starts the node, and keeps it running until you stop it (Ctrl+C).

---

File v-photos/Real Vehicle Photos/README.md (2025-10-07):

RUWANCE (1)

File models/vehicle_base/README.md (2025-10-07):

RUWANCE (2)

Vehicle Base

This piece is the **main platform of our vehicle**. It supports all the main componentslike the the Raspberry Pi, LiDAR, and camera housings. It was **laser-cut from MDF**, which gives it a good balance between strength and lightness. The design includes **placed holes** for screwing in the electronic and mechanical parts.

For the fabrication process, we started by sketching the base on squared paper and then prototyping it on cardboard. We used acrylic to test the dimensions on our first models. After confirming the fit, we finalized the design in Fusion 360 and cut it in MDF for the final version. 

<br>

<p align = "center">
  
</p>

> [!NOTE]
> This was our previous chassis design. It consisted of a base and upper casing that were crafted from aluminum. The base was designed to mount the Raspberry Pi and support the weight of the vehicle’s systems. The upper casing, which houses the LiDAR sensor, was designed to ensure the sensor has an unobstructed view. Still, having the components packed wasn't efficient for immediate modifications, which is why we changed it.
> 

**Model Details**
- Format: `.stl` (Fusion 360 export)
- Material: MDF
- Layer height: 0.2 mm (if 3D printed)
- Support: Not required

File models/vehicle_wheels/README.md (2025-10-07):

RUWANCE

LVehicle Wheels

This is our front wheel design. Although we use standard Hi-Wonder Kit wheels at the back, we noticed that the front wheels were sticking out of the chassis too much, making the robot wider. To solve this, we decided to 3D print custom wheels with a 6 mm diameter.

Initially, we used them without any rubber or friction border, but the car couldn’t move properly. Later, we added a wheel border to increase traction, and everything worked perfectly. To give the robot a unique look, we also integrated the Robotek logo (the koala) into the wheel design.

**Model Details**
- Format: `.stl`
- Material: PLA
- Layer height: 0.20 mm
- Infill: 25%
- Supports: Yes, for internal cavities

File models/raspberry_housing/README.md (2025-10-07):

RUWANCE (1)

Raspberry Housing

We designed this structure as a **space-efficient housing** that could hold the **RRC Lite Controller** with the **Raspberry Pi 5**, our **7.4 V batteries**, and the L298N Motor Driver at the back. The design integrates components vertically to reduce the length of the car.

**Design Highlights**
- Vertical design that saves horizontal space within the vehicle chassis.  
- Holds the Raspberry Pi and RRC Controller securely in stacked alignment.  
- Integrated compartment for battery placement underneath.
- Includes screw holes at the back for the motor driver. 

**Model Details**
- Format: `.stl`
- Material: PLA
- Layer height: 0.16 mm
- Infill: 20%
- Supports: Minimal (internal)

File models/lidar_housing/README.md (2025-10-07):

RUWANCE

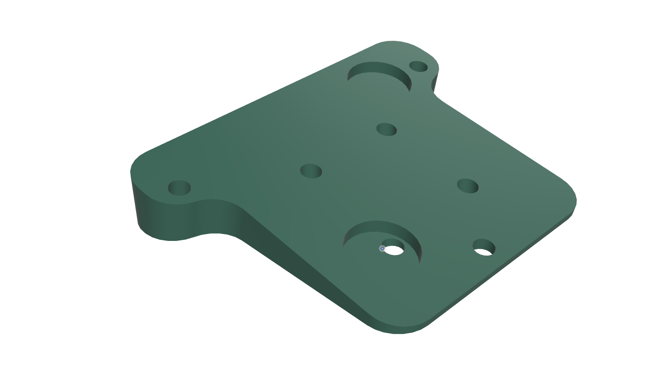
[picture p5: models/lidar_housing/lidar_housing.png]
LiDAR Housing


This part works as the mount for the LiDAR sensor. It’s built with a slight incline to give the sensor a better scanning angle and improve how it measures distances from walls. The design includes screw holes that let it attach firmly to both the vehicle base and the LiDAR itself, keeping everything stable while the robot is moving.

**Model Details**
- Format: `.stl`
- Material: PLA
- Layer height: 0.20 mm
- Infill: 25%
- Supports: Yes, for internal cavities

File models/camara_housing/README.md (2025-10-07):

<p align="center">
  
</p>

<p align="center">
  
</p>

This component holds our DOF camera. It ensures a correct viewing of the obstacles thanks to the inclination angle. The mount features screw holes and is designed to fit the front section of the robot chassis.

**Model Details**
- Format: `.stl`
- Material: PLA
- Layer height: 0.16 mm
- Infill: 25%
- Supports: Required (base only)

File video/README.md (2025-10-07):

RUWANCE (3)

<br>
<br>

<div align="center">

| Challenge | YouTube Video |
|---|---|
| **Open Challenge** | [Watch on YouTube 🎥](https://www.youtube.com/watch?v=iRfN6pBE0Ac) |
| **Obstacle Challenge** | [Watch on YouTube 🎥](https://www.youtube.com/watch?v=5Ic2xejqBcA) |

</div>

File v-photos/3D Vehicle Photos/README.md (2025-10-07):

RUWANCE

| Front | Left | Right |
|:--:|:--:|:--:|
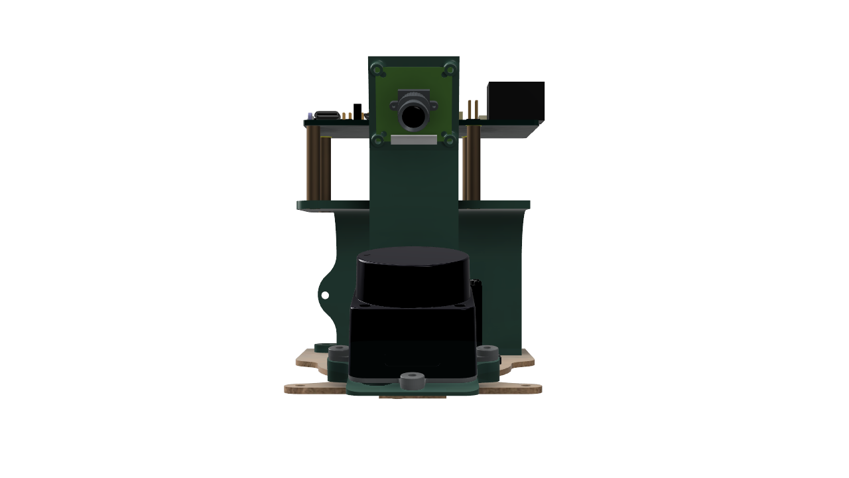
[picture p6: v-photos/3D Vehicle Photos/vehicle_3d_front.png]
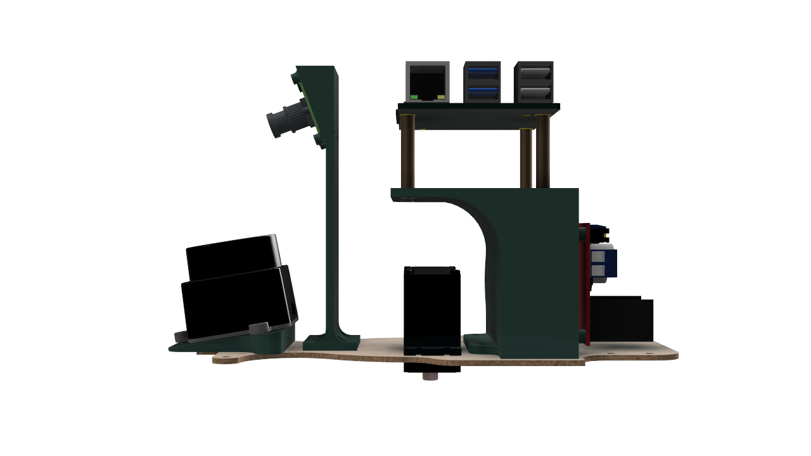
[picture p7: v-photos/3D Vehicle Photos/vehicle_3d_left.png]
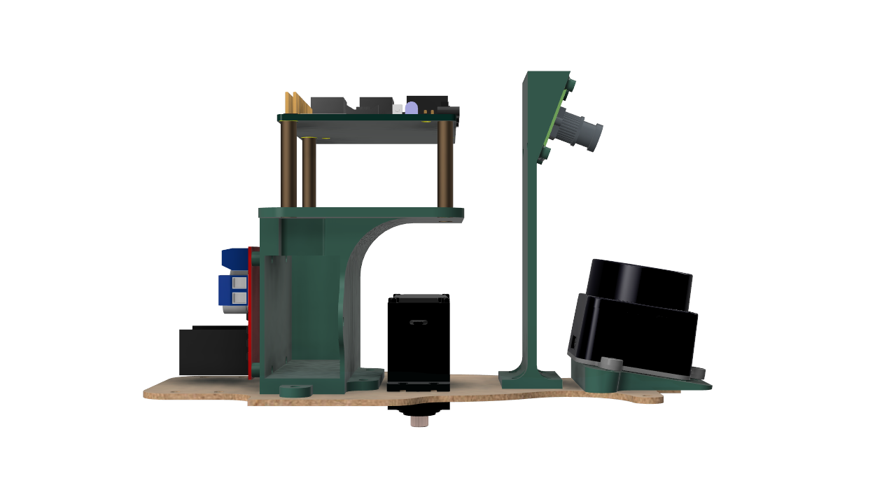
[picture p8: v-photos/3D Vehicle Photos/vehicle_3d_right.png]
|  |  |  |

| Back | Top | Bottom |
|:--:|:--:|:--:|
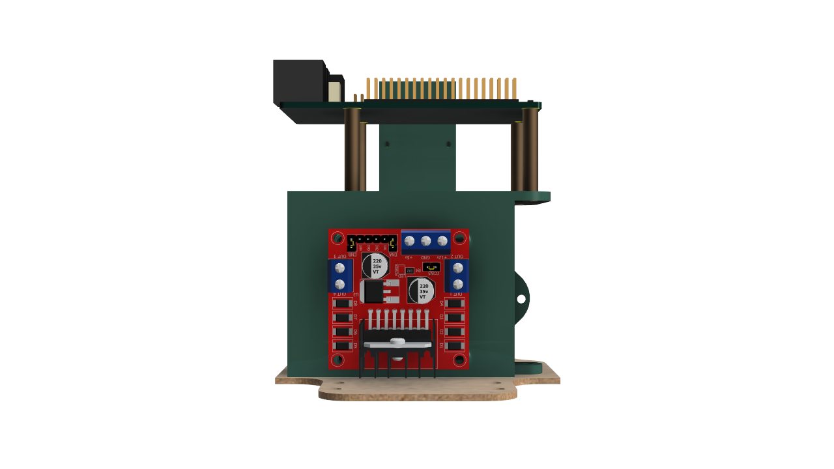
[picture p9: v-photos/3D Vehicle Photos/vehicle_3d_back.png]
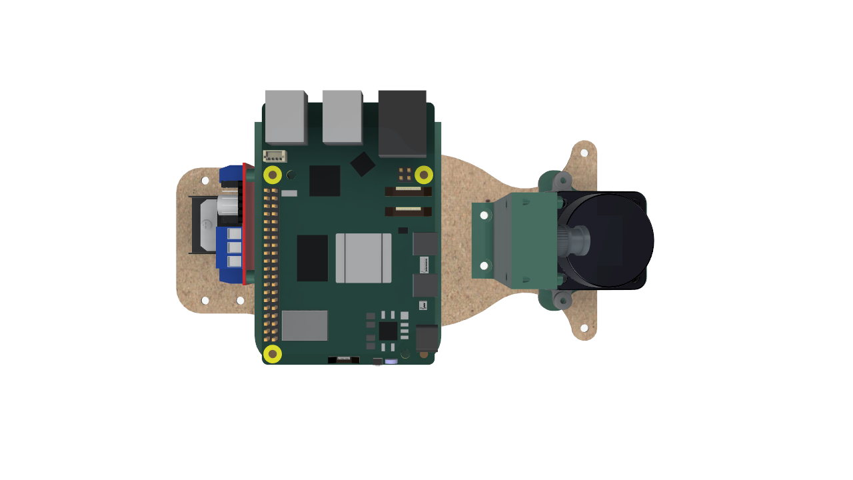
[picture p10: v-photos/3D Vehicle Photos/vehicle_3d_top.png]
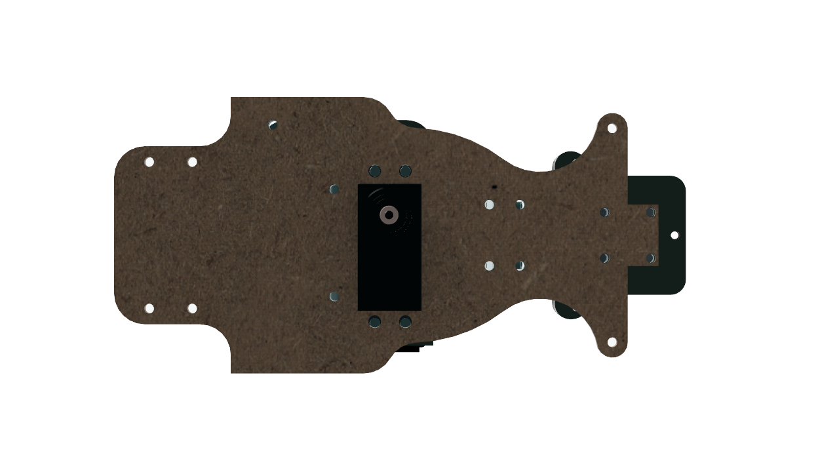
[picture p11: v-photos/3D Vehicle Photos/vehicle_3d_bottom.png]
|  |  |  |

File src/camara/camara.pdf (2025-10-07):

#!/usr/bin/env python3

import rclpy
from rclpy.node import Node
from rclpy.qos import QoSProfile, ReliabilityPolicy, HistoryPolicy from sensor_msgs.msg import Image
from std_msgs.msg import String
from cv_bridge import CvBridge
import cv2
import numpy as np

class ColorObstacleDetector(Node):
"""
Suscribe: /usb_cam/image_raw
Publica : /obstaculos -> "rojo" | "verde" | "libre"
- Sensibilidad reducida (HSV estricto, min_area alto, N frames consecutivos)
- RetenciГіn: mantiene el Гєltimo color por 'hold_seconds' si desaparece """

def __init__(self):
super().__init__('color_obstacle_detector')

# --- ParГЎmetros de sensibilidad ---

self.declare_parameter('min_area', 1400) | # p -xeles m -nimos
self.declare_parameter('consecutive_required', 3) | # N frames seguidos
self.declare_parameter('hold_seconds', 1.0) | # retenciГіn tras perder color
self.min_area = int(self.get_parameter('min_area').value) self.consecutive_required = int(self.get_parameter('consecutive_required').value) self.hold_seconds = float(self.get_parameter('hold_seconds').value)

# --- Umbrales HSV mГЎs estrictos ---

# Verde

self.lower_green = np.array([45, 0, 0], dtype=np.uint8) self.upper_green = np.array([85, 255, 255], dtype=np.uint8) # Rojo (dos rangos)
self.lower_red1 = np.array([0, 50, 50], dtype=np.uint8) self.upper_red1 = np.array([8, 255, 255], dtype=np.uint8) self.lower_red2 = np.array([170, 40, 40], dtype=np.uint8) self.upper_red2 = np.array([179, 255, 255], dtype=np.uint8)

self.bridge = CvBridge()

image_qos = QoSProfile(
reliability=ReliabilityPolicy.BEST_EFFORT, history=HistoryPolicy.KEEP_LAST, depth=10,
)

self.image_sub = self.create_subscription(
Image, '/usb_cam/image_raw', self.image_callback, image_qos )
self.pub = self.create_publisher(String, '/obstaculos', 10)

# Estado para "N consecutivos" y retenciГіn self.green_count = 0

self.red_count = 0
self.last_label = 'libre'
self.last_detect_time = None # segundos (float)

self.get_logger().info(
f'ColorObstacleDetector listo (min_area={self.min_area}, ' f'consecutive_required={self.consecutive_required}, hold_seconds={self.hold_seconds}).' )

def now_s(self) -> float:
return self.get_clock().now().nanoseconds / 1e9

def image_callback(self, msg: Image):
try:
frame = self.bridge.imgmsg_to_cv2(msg, desired_encoding='bgr8') except Exception as e:
self.get_logger().error(f'CvBridge error: {e}')
return

hsv = cv2.cvtColor(frame, cv2.COLOR_BGR2HSV)

# MГЎscaras

mask_green = cv2.inRange(hsv, self.lower_green, self.upper_green) mask_red = cv2.bitwise_or(
cv2.inRange(hsv, self.lower_red1, self.upper_red1), cv2.inRange(hsv, self.lower_red2, self.upper_red2)
)

# Morfolog -a fuerte para reducir ruido

kernel = np.ones((7, 7), np.uint8)
mask_green = cv2.morphologyEx(mask_green, cv2.MORPH_OPEN, kernel, iterations=2) mask_green = cv2.morphologyEx(mask_green, cv2.MORPH_CLOSE, kernel, iterations=2) mask_red = cv2.morphologyEx(mask_red, cv2.MORPH_OPEN, kernel, iterations=2) mask_red = cv2.morphologyEx(mask_red, cv2.MORPH_CLOSE, kernel, iterations=2)

# ГЃreas mГЎximas

green_area = self._max_contour_area(mask_green)
red_area = self._max_contour_area(mask_red)

green_ok = green_area >= self.min_area
red_ok = red_area >= self.min_area

# Debounce por frames consecutivos

self.green_count = self.green_count + 1 if green_ok else 0
self.red_count | = self.red_count + 1 | if red_ok | else 0

g_ready = self.green_count >= self.consecutive_required r_ready = self.red_count >= self.consecutive_required

decided_label = 'libre'
now = self.now_s()

if g_ready or r_ready:
# DetecciГіn vГЎlida: elegir color y actualizar "Гєltimo visto" if g_ready and r_ready:

decided_label = 'rojo' if red_area >= green_area else 'verde' elif r_ready:
decided_label = 'rojo'
else:
decided_label = 'verde'
self.last_label = decided_label
self.last_detect_time = now
else:
# Sin detecciГіn actual: ВїaГєn dentro de la ventana de retenciГіn?

if self.last_detect_time is not None and (now - self.last_detect_time) <= self.hold_seconds: decided_label = self.last_label # mantener Гєltimo color
else:
decided_label = 'libre'

self.last_label = 'libre'
self.last_detect_time = None

self.pub.publish(String(data=decided_label))
self.get_logger().info(f"/obstaculos: {decided_label} (red={red_area}, green={green_area})")

@staticmethod
def _max_contour_area(mask: np.ndarray) -> int:
contours, _ = cv2.findContours(mask, cv2.RETR_EXTERNAL, cv2.CHAIN_APPROX_SIMPLE) return 0 if not contours else int(max(cv2.contourArea(c) for c in contours))

def main(args=None):
rclpy.init(args=args)
node = ColorObstacleDetector() try:
rclpy.spin(node)
except KeyboardInterrupt:
pass
finally:
node.destroy_node()
rclpy.shutdown()

if __name__ == '__main__': main()

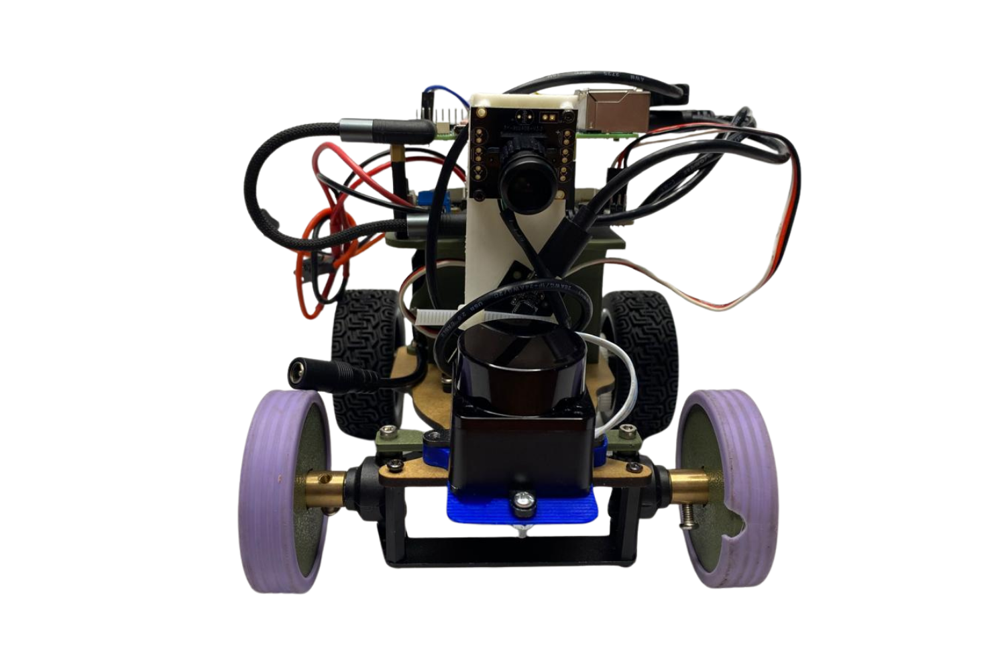
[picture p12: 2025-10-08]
v-photos/Real Vehicle Photos/vehicle_front.png

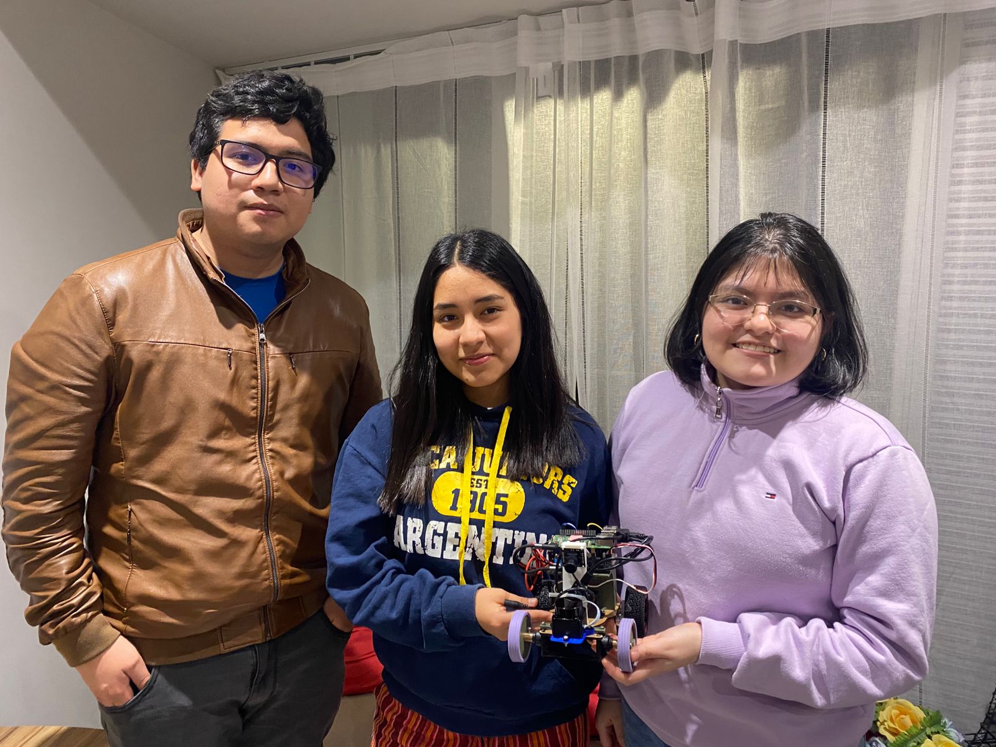
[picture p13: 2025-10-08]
t-photos/official_photo.jpg

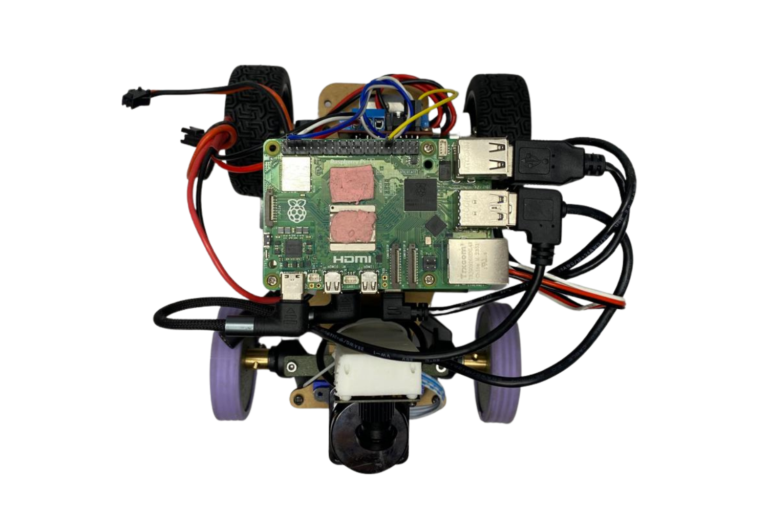
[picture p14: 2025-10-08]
v-photos/Real Vehicle Photos/vehicle_top.png

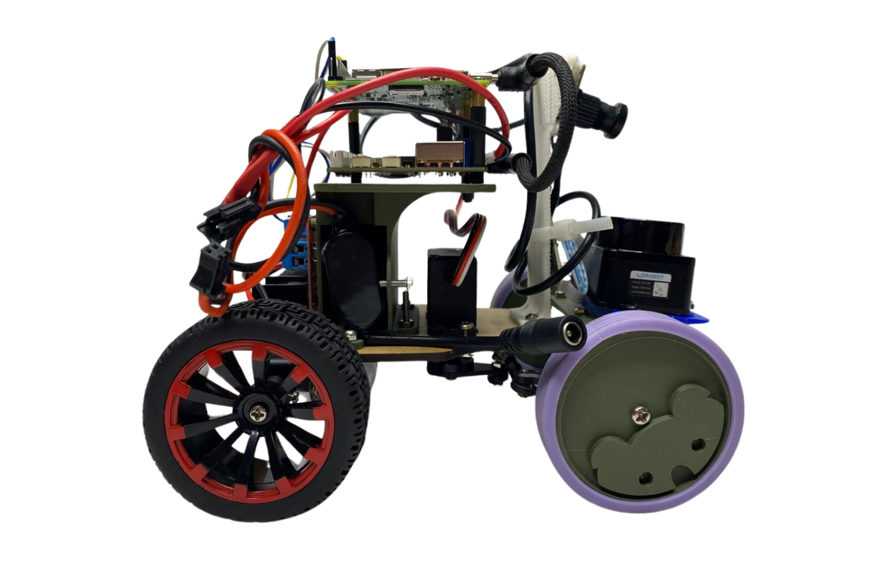
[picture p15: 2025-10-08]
v-photos/Real Vehicle Photos/vehicle_right.png

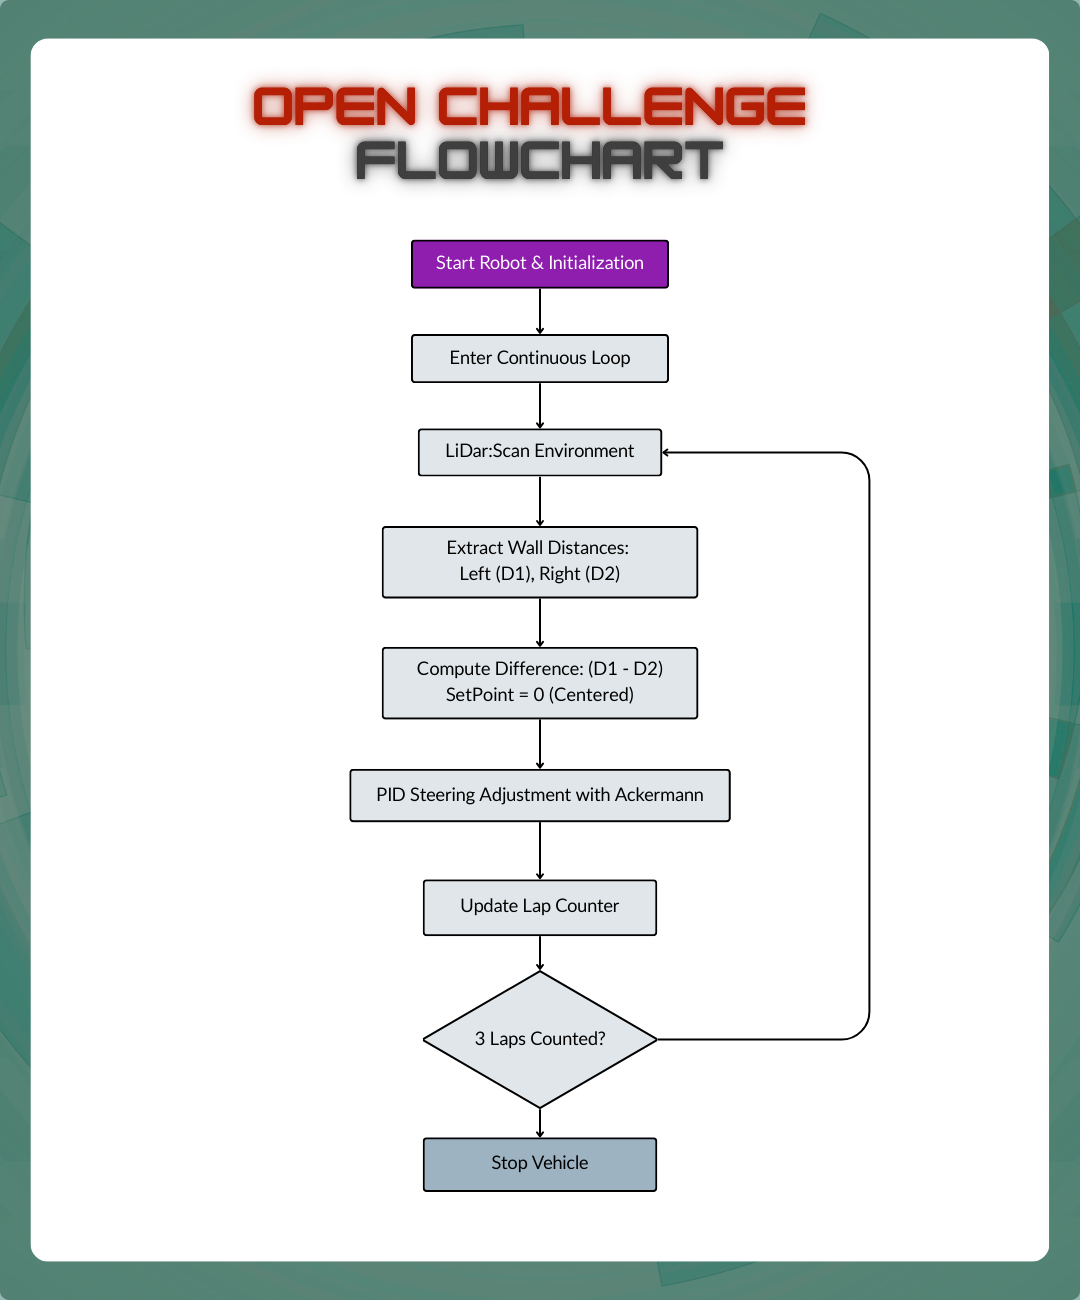
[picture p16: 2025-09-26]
schemes/open_challenge_flowchart.png

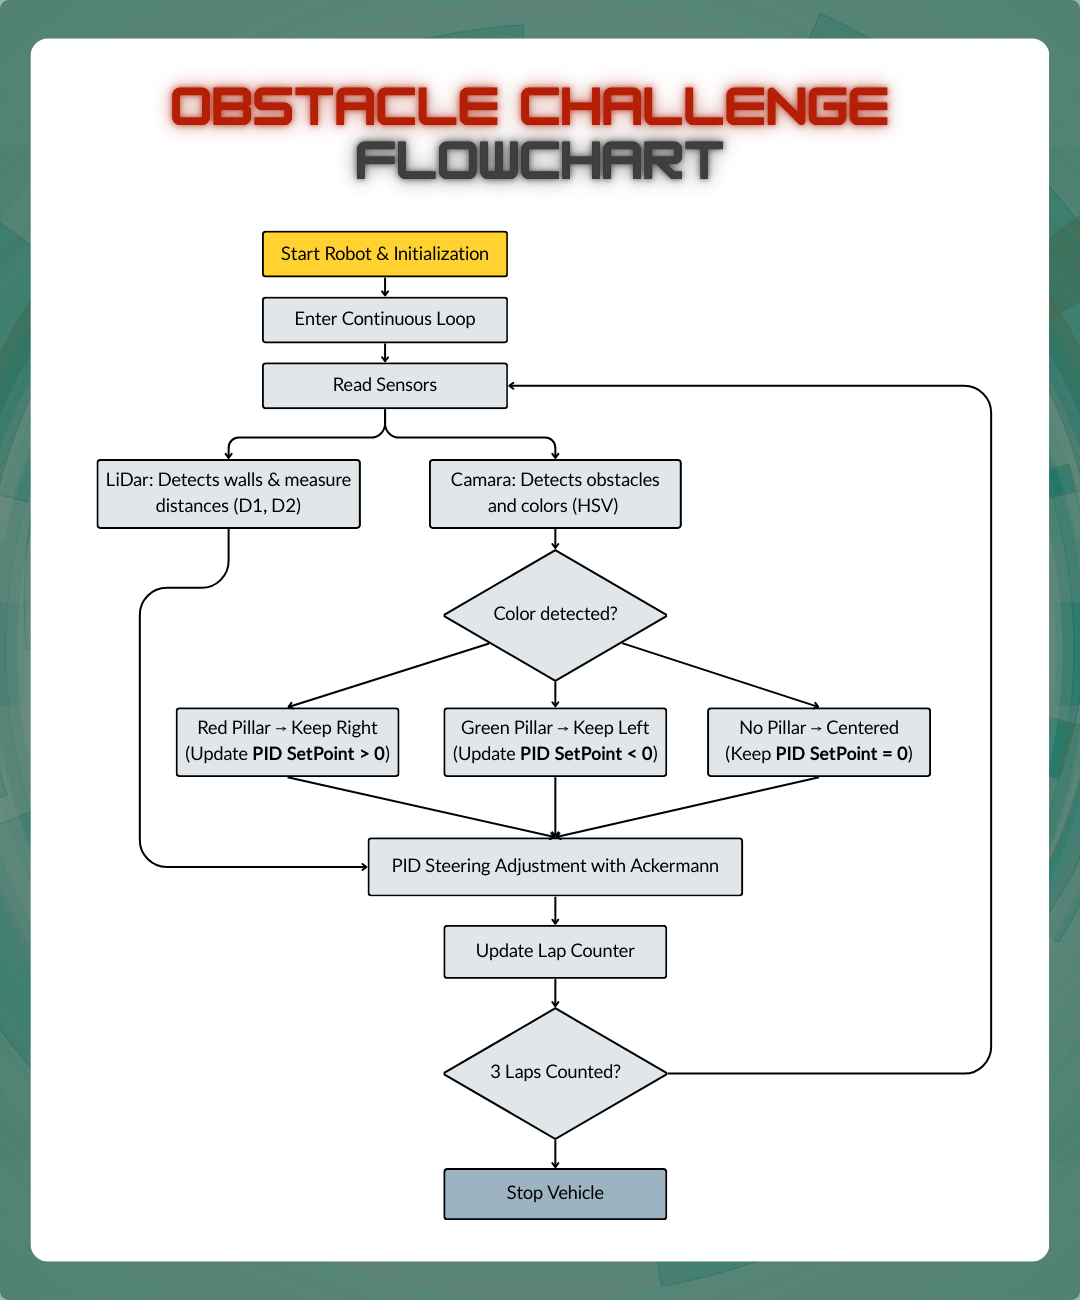
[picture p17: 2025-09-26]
schemes/obstacle_challenge_flowchart.png

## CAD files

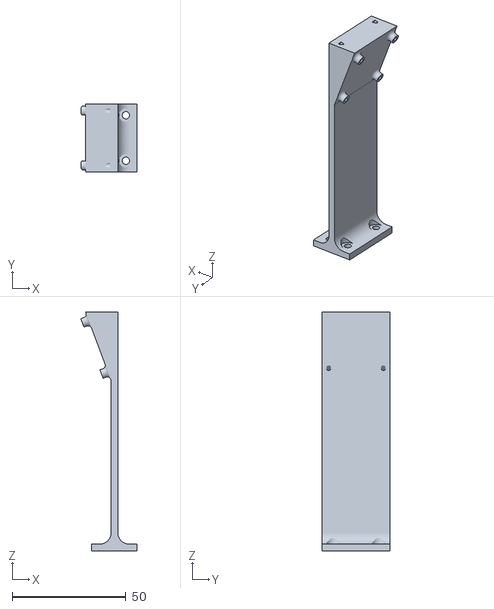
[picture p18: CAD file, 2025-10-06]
models/camara_housing/camara_housing.stl
24.8 x 30.0 x 105.0

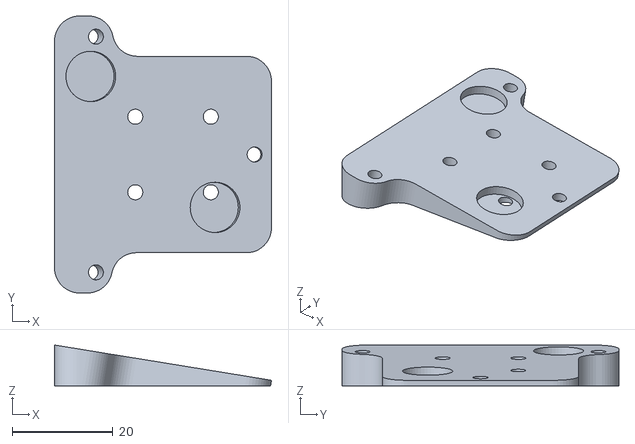
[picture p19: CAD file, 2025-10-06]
models/lidar_housing/lidar_housing.stl
43.1 x 55.0 x 8.13

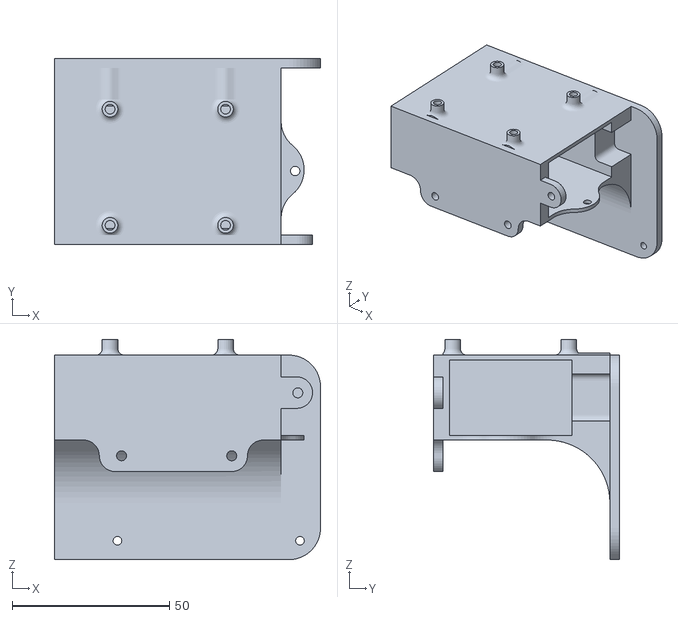
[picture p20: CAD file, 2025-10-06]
models/raspberry_housing/raspberry_housing.stl
84.5 x 59.0 x 70.0

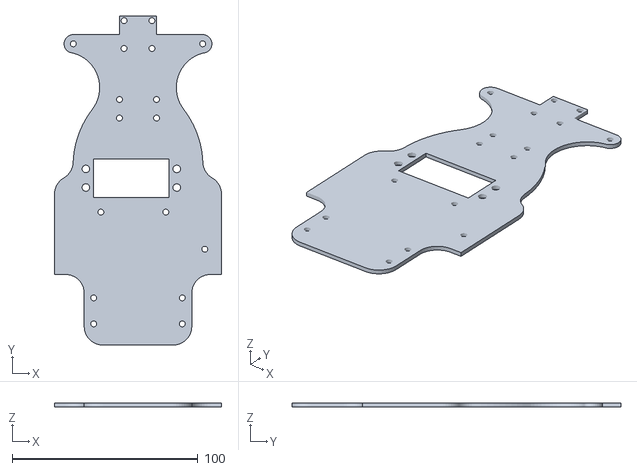
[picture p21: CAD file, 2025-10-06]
models/vehicle_base/vehicle_base.stl
90.0 x 177.3 x 2.00

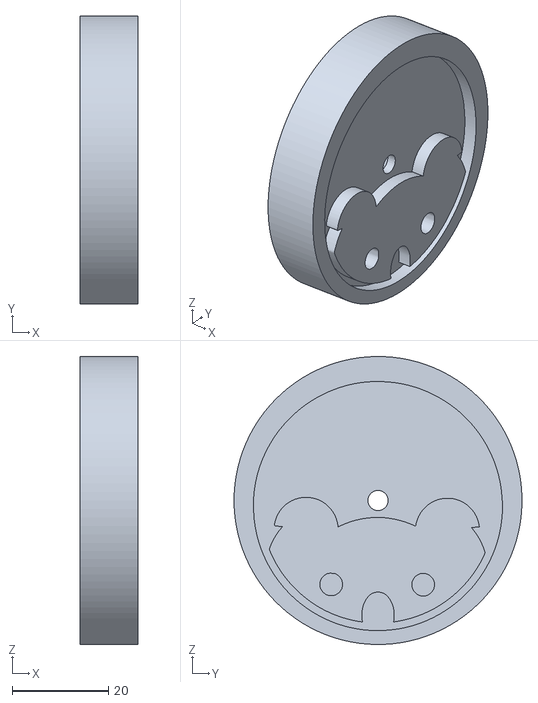
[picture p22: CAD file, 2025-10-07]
models/vehicle_wheels/vehicle_wheels.stl
12.0 x 60.0 x 60.0

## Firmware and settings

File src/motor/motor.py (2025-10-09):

#!/usr/bin/env python3
from rclpy.node import Node
from std_msgs.msg import Float32
import lgpio
import time
import threading
import rclpy


class MotorPWMNode(Node):
    def __init__(self):
        super().__init__('motor_pwm_node')

        # Configuración GPIO
        self.CHIP = 4
        self.PWM_PIN = 12  # BCM18 (pin físico 12)
        self.freq = 1000  # Hz
        self.period = 1 / self.freq
        self.duty = 0.0  # duty [0.0 - 1.0]

        # Inicializar GPIO
        self.h = lgpio.gpiochip_open(self.CHIP)
        lgpio.gpio_claim_output(self.h, self.PWM_PIN)

        # Suscriptor
        self.subscription = self.create_subscription(
            Float32,
            '/motor_vel',
            self.vel_callback,
            10
        )

        # Hilo para generar PWM
        self.running = True
        self.pwm_thread = threading.Thread(target=self.pwm_loop)
        self.pwm_thread.start()

        self.get_logger().info("MotorPWMNode iniciado. Escuchando en /motor_vel (0-100).")

    def vel_callback(self, msg):
        # Escala 0-100 a 0.0-1.0
        self.duty = max(0.0, min(1.0, msg.data / 100.0))
        self.get_logger().info(f"Duty actualizado: {self.duty * 100:.1f}%")

    def pwm_loop(self):
        while self.running:
            if self.duty > 0:
                lgpio.gpio_write(self.h, self.PWM_PIN, 1)
                time.sleep(self.period * self.duty)
                lgpio.gpio_write(self.h, self.PWM_PIN, 0)
                time.sleep(self.period * (1 - self.duty))
            else:
                lgpio.gpio_write(self.h, self.PWM_PIN, 0)
                time.sleep(self.period)

    def destroy_node(self):
        self.running = False
        self.pwm_thread.join()
        lgpio.gpio_write(self.h, self.PWM_PIN, 0)
        lgpio.gpiochip_close(self.h)
        super().destroy_node()


def main(args=None):
    rclpy.init(args=args)
    node = MotorPWMNode()
    try:
        rclpy.spin(node)
    except KeyboardInterrupt:
        pass
    finally:
        node.destroy_node()
        rclpy.shutdown()


if __name__ == '__main__':
    main()
